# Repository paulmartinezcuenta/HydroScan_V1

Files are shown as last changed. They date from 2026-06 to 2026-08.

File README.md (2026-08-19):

<div align="center">

#  Mechatronics & IoT Engineering Projects

*Centralized repository for the development of unified embedded systems.*






</div>

---

> **💡 Manufacturing Note:** To drastically optimize industrial production costs, the PCBs for both projects (HydroScan and AUTOAMBU) have been unified into a single manufacturing panel (Panelized Gerber), sharing the same manufacturing cycle.

---

##  Project 1: HydroScan (Maritime IoT Node)
**Smart buoy for real-time water quality monitoring.***

<p align="center">
  
  
  
  
</p>

* 📡 **Telemetry:** Real-time environmental data transmission via LTE networks.
* 📍 **Tracking:** Integrated GPS geolocation for precise positioning of the node.
* 🔋 **Power:** Self-sustaining energy system utilizing solar panels to charge and monitor the sensors autonomously.
* 🔬 **Application:** Oceanographic research and environmental monitoring in coastal areas.
* 📁 [**Explore HydroScan Firmware ➔**](./Firmware_HydroScan)

---

## 🫁 Project 2: AUTOAMBU (Automated Respirator)
**Automated respiratory assistance system.**

<p align="center">
  
  
  
  
</p>

* ⚙️ **Actuation & Control:** Precision mechanical control using a DC motor equipped with an encoder and driven by an L298N H-bridge.
* ⚡ **Power Management:** USB Super Fast Charging architecture designed to simultaneously power the circuitry and charge the system.
* 🧠 **Architecture:** Centralized ESP32 32U control logic with dedicated thermal management for continuous and safe operation.
* 📁 [**Explore AUTOAMBU Firmware ➔**](./Firmware_AUTOAMBU)

---

## 👥 Development Team

* ⚡ **Paul** - Hardware Design and PCB Routing 
* 🏗️ **Miguel** - Structural 3D Design
* 💻 **Isaias** - Firmware Development
* 💻 **Alberto** - Firmware Development

---

## 📂 Repository Architecture

| Directory | Description |
| :--- | :--- |
| 🖨️ [**`Hardware_Panelized/`**](./Hardware_Panelized) | Unified KiCad project and joint production Gerber files ready for manufacturing. |
| 💻 [**`Firmware_AUTOAMBU/`**](./Firmware_AUTOAMBU) | Source code (C/C++) and control routines for the medical respirator. |
| 📡 [**`Firmware_HydroScan/`**](./Firmware_HydroScan) | Telemetry logic and sensor reading for the maritime buoy. |
| 📚 [**`Docs/`**](./Docs) | Technical documentation, datasheets, schematics, and 3D models for both systems. |

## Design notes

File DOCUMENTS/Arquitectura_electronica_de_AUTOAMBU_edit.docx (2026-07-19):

Diseño de la estructura electrónica del sistema AUTOAMBU

4.2 Arquitectura electrónica del sistema

Aquí incluirías un diagrama de bloques, no la PCB.

Se explicaría cómo está organizado el sistema:

- Unidad de alimentación.
- Regulación de voltaje.
- Unidad de procesamiento (ESP32).
- Etapa de potencia.
- Sensores.
- Interfaz de usuario.
- Comunicaciones.

4.3 Criterios de diseño de la PCB

Este apartado explica cómo diseñaste la tarjeta antes de hablar de componentes específicos.

Aquí describirías aspectos como:

- Diseño basado en criterios DFM (Design for Manufacturing).
- Cumplimiento de normas IPC.
- Selección del stack-up de la PCB.
- Distribución de bloques funcionales.
- Separación entre potencia y lógica.
- Integridad de señal.
- Integridad de potencia.
- Compatibilidad electromagnética (EMC).

4.4 Distribución física de los componentes

En este apartado ya comenzarías a justificar decisiones concretas.

Por ejemplo:

La distribución física de los componentes se realizó considerando la función eléctrica de cada subsistema y las recomendaciones de diseño establecidas por los fabricantes. Los bloques encargados de la regulación de potencia fueron ubicados próximos a la entrada de alimentación, mientras que la unidad de procesamiento se situó en una región separada de las fuentes de ruido eléctrico generadas por los convertidores conmutados.

Luego explicarías:

- por qué el ESP32 está donde está;
- por qué el regulador está cerca del conector de alimentación;
- por qué los conectores se colocaron en los bordes;
- por qué el driver del motor está cerca del motor.

4.5 Diseño del sistema de alimentación

Aquí entrarías en detalles como:

- Regulador Buck.
- Fuente de 3.3 V.
- Capacitores.
- Diodo Schottky.
- Bobina.
- Anchos de pista.
- Plano de alimentación.

Aquí iría la explicación que hicimos anteriormente sobre el diseño del convertidor Buck.

4.6 Diseño del plano de tierra (Ground Plane)

Este apartado es muy importante porque tu PCB tiene bastante trabajo en ese aspecto.

Podrías explicar:

- plano continuo de tierra;
- retorno de corriente;
- reducción de EMI;
- reducción de impedancia;
- estabilidad del sistema;
- conexión entre capas mediante vías.

4.7 Estrategias de integridad de señal y potencia

Aquí describirías decisiones como:

- capacitores de desacoplo de 100 nF;
- capacitor de 10 µF junto al ESP32;
- pistas cortas;
- reducción del área del lazo de corriente;
- separación entre señales digitales y potencia;
- ubicación del regulador conmutado;
- distribución de planos de alimentación.

4.8 Gestión térmica

En este apartado hablarías de:

- vías térmicas (thermal vias o via-in-pad);
- disipación mediante planos de cobre;
- componentes de potencia;
- reducción de temperatura.

4.9 Diseño orientado a manufactura (DFM)

Aquí explicarías:

- cumplimiento de reglas DRC;
- cumplimiento de capacidades del fabricante (por ejemplo, JLCPCB);
- separación mínima entre pistas;
- diámetros de vías;
- tamaño de pads;
- serigrafía;
- panelización (si aplica).

4.10 Validación del diseño

Finalmente, cerrarías el capítulo indicando cómo verificaste el diseño antes de fabricar la placa:

- revisión del esquemático;
- comprobación de reglas eléctricas (ERC);
- comprobación de reglas de diseño (DRC);
- revisión del modelo 3D;
- generación de archivos Gerber;
- fabricación y ensamblaje.

CAPÍTULO IV

Diseño de la estructura electrónica del sistema AUTOAMBU

Introducción

El sistema AUTOAMBU fue concebido como un asistidor respiratorio automatizado capaz de controlar el proceso de compresión de un resucitador manual tipo Ambu mediante una plataforma electrónica integrada. El diseño electrónico constituye el núcleo del sistema, ya que es responsable de coordinar la adquisición de datos, el procesamiento de información, el control de los actuadores y la administración de la alimentación eléctrica, garantizando un funcionamiento estable y seguro.

El desarrollo de la arquitectura electrónica se realizó bajo criterios de confiabilidad, modularidad y facilidad de manufactura, buscando minimizar las pérdidas eléctricas, mejorar la inmunidad frente al ruido electromagnético y optimizar la distribución térmica de los componentes de potencia. Para alcanzar estos objetivos se empleó el software KiCad como herramienta de diseño asistido por computadora (CAD), permitiendo desarrollar el esquema eléctrico, la placa de circuito impreso (PCB) y la documentación necesaria para su fabricación.

Durante el diseño se aplicaron criterios basados en las recomendaciones de las normas IPC para el dimensionamiento de pistas, separación entre conductores, distribución de componentes y uso de planos de tierra, así como las guías de diseño proporcionadas por los fabricantes de los principales circuitos integrados utilizados en el sistema. Estas prácticas permitieron obtener una tarjeta electrónica orientada a manufactura, con un alto nivel de integración y preparada para operar de manera confiable en aplicaciones de control embebido.

Figura #_#. Diseño final de la placa de circuito impreso (PCB) del sistema AUTOAMBU.

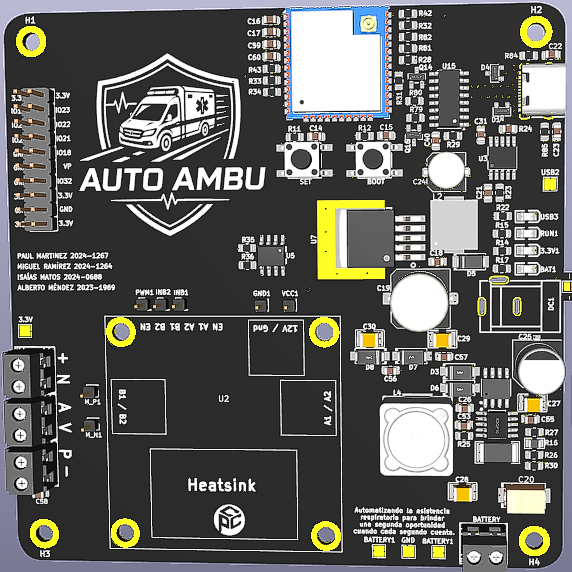
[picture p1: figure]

titulo

Arquitectura electrónica del sistema

Interfaz de entrada y negociación de potencia (USB Tipo-C)

Introducción El sistema AUTOAMBU emplea un conector USB Tipo-C de 16 pines como interfaz principal para la alimentación eléctrica del circuito. A diferencia de las implementaciones convencionales que operan a 5 V, este diseño incorpora un sistema de Power Delivery (PD) destinado a satisfacer las mayores demandas energéticas requeridas por la etapa de potencia y el accionamiento de los actuadores del dispositivo médico. El uso de este estándar garantiza una alta confiabilidad mecánica, reversibilidad de conexión y la capacidad de manejar mayores densidades de corriente.

Colocar imagen del apartado del USB

Negociación de potencia (Power Delivery) Para gestionar los requerimientos energéticos, el circuito incluye el circuito integrado CH224K, un controlador lógico (Sink Controller) diseñado para el protocolo USB Power Delivery. Este dispositivo se interconecta con las líneas de configuración del conector (CC1 y CC2) para establecer comunicación con la fuente externa y solicitar de manera activa un perfil de carga rápida.

Mediante la configuración por hardware de sus pines de control (CFG1, CFG2 y CFG3), el controlador CH224K negocia una salida nominal de 15 V y una capacidad de corriente de hasta 3A. El pin Power Good (PG) se utiliza para señalizar el estado de la negociación hacia las siguientes etapas del sistema, garantizando que los reguladores posteriores solo operen cuando la fuente haya estabilizado la tensión solicitada.

Protección eléctrica y compatibilidad electromagnética (EMC) Considerando la naturaleza de la aplicación médica y los riesgos asociados a transitorios eléctricos durante la conexión del cable, la etapa de entrada fue diseñada con múltiples barreras de protección de estado sólido y filtrado pasivo:

- Supresión de transitorios (TVS): Se implementaron arreglos de diodos supresores de voltaje transitorio (TVS), modelo SM05.TCT, conectados estratégicamente a la línea de alimentación principal y a los canales de comunicación. Los diodos D1 y D4 actúan absorbiendo las descargas electrostáticas (ESD) y limitando los picos de sobretensión tanto en VBUS (V5_1 en el esquemático) como en las líneas CC1 y CC2, derivando la energía perjudicial hacia el plano de tierra antes de que alcance el controlador CH224K o el resto de los componentes sensibles.
- Aislamiento del chasis (Shield Grounding): Para mitigar la interferencia electromagnética (EMI), la carcasa metálica del conector (pines EH) no se conectó rígidamente al plano de tierra del sistema (GND). En su lugar, se diseñó una red de acoplamiento RC en paralelo, compuesta por capacitores de desacoplo de 0.1 µF y resistencias de 1 MΩ (R85 y R84). Esta topología permite drenar de forma segura las interferencias de radiofrecuencia (RF) captadas por el blindaje del cable, a la vez que previene la formación de lazos de tierra (ground loops) de baja frecuencia que podrían afectar la estabilidad analógica del circuito.

Etapa 2

Sistema de gestión de carga y selección de alimentación (Power Path)

Introducción La energía de 15 V proveniente del controlador de Power Delivery se dirige a la etapa de gestión de energía, la cual tiene dos propósitos fundamentales: administrar de manera segura el perfil de carga del paquete de baterías de iones de litio en configuración 3S (12.6 V) y garantizar la continuidad del suministro eléctrico hacia el resto del dispositivo (sistema Power Path).

Colocar imagen del apartado de carga:

Esquemático del circuito de carga basado en el controlador CN3795 y arreglo de diodos para selección de alimentación.

x

CN3795

Para el control de carga se seleccionó el circuito integrado CN3795, un controlador de carga de amplio rango de entrada que opera mediante una topología de conmutación tipo Buck (reductor). Este controlador acciona un MOSFET de canal P (Q1, modelo AO4435) que, en conjunto con el diodo de captura Schottky (D6) y el inductor de potencia (L4, 22 µH), conforma la etapa de potencia encargada de reducir los 15 V de entrada a los 12.6 V requeridos por la batería.

El control del voltaje de flotación se establece a través de un divisor resistivo de precisión (R16 y R27) conectado al pin de retroalimentación (FB). Simultáneamente, la corriente de carga máxima se regula mediante la resistencia de sensado (R13) ubicada entre los pines CSP y BAT del integrado. Este lazo de control dual permite al CN3795 ejecutar las fases de carga de corriente constante (CC) y voltaje constante (CV) exigidas por la química de litio, maximizando la vida útil de las celdas.

Estrategia de aislamiento de tierras (Clean Ground) Un aspecto crítico en el diseño de esta etapa fue la mitigación del ruido eléctrico. Dado que el convertidor de conmutación genera corrientes transitorias de alta frecuencia (di/dt), se implementó una estrategia de tierras separadas para proteger las mediciones analógicas del controlador. Como se observa en el esquemático, se definió una red de "tierra limpia" (GND2) para los pines de referencia del CN3795. Esta red se une al plano de tierra principal de potencia (GND) en un único punto mediante un componente físico de unión o Net Tie (NT1). Esta técnica, conocida como conexión en estrella, evita que las corrientes de retorno de la etapa de potencia circulen por la sección analógica, garantizando una regulación estable.

Gestión de distribución de energía (Power Path) Para asegurar que el sistema AUTOAMBU no se interrumpa al desconectar el cable USB, se diseñó un circuito de selección de fuente de alimentación basado en un arreglo de diodos en configuración OR (D7 y D8).

- Operación con alimentación externa: Cuando el dispositivo está conectado por USB (V5_1 activo a 15 V), el diodo D7 conduce y suministra energía directamente al nodo principal de regulación (VCC_REG). Dado que los 15 V de entrada son superiores a los 12.6 V máximos de la batería, el diodo D8 queda polarizado en inversa, bloqueando el flujo y permitiendo que toda la corriente del cargador se destine exclusivamente a recargar la batería.
- Operación a batería: Al desconectar el cable USB, la tensión V5_1 cae a cero. Inmediatamente, el diodo D8 queda polarizado en directa, permitiendo que la batería asuma la carga del sistema de manera ininterrumpida.

Finalmente, es importante destacar que la alimentación para el actuador mecánico principal (VCC_MOTOR) se extrajo directamente del nodo de la batería y antes del arreglo de diodos. Esta decisión de diseño aísla las severas caídas de tensión y el ruido inductivo generados por los picos de arranque del motor de corriente continua, protegiendo así la estabilidad del nodo de regulación lógica (VCC_REG).

Etapa de regulación lógica (Convertidor Buck 3.3 V)

Introducción La tensión proveniente del bus principal de alimentación (VCC_REG), la cual puede variar entre los aproximadamente 9 V de una batería próxima a descargarse y los 15 V suministrados por el adaptador USB Tipo-C, debe ser reducida y estabilizada para alimentar de forma segura al microcontrolador ESP32 y a la instrumentación de baja potencia. Debido a la considerable diferencia de potencial entre la entrada y la salida requerida, se descartó el uso de reguladores lineales (LDO), ya que generarían una disipación térmica excesiva e ineficiente. En su lugar, se implementó un convertidor de conmutación tipo Buck.

Incluir imagen de la etapa del regulador

Esquemático del regulador reductor LM2576HVS-3.3 para la alimentación del ESP32.

Selección del regulador y filtrado de entrada El núcleo de esta etapa es el circuito integrado monolítico LM2576HVS-3.3 (U7), seleccionado por su robustez, su amplio margen de voltaje de entrada (versión HVS) y su capacidad para suministrar hasta 3 A de corriente continua, garantizando un margen de potencia holgado para los picos de transmisión de radiofrecuencia del ESP32.

Para estabilizar la entrada del regulador, se implementó una red de filtrado desacoplada. El capacitor C19 (470 µF) actúa como un depósito de energía (bulk capacitor) que absorbe los transitorios de baja frecuencia y previene caídas abruptas en el bus VCC_REG durante los ciclos de encendido del regulador. En paralelo, el capacitor cerámico C18 (100 nF) se ubicó lo más cerca posible del pin de entrada (Vin) para derivar a tierra el ruido de alta frecuencia y las interferencias electromagnéticas.

Red de conmutación y salida El proceso de conversión de energía se lleva a cabo mediante la interacción del interruptor interno del LM2576, el inductor L2 (100 µH) y el diodo de captura D5 (B330A).

- Diodo Schottky: La selección del diodo B330A es crítica en esta topología. Al ser un diodo de barrera Schottky, posee un tiempo de recuperación inversa prácticamente nulo y una baja caída de tensión directa. Esto permite que la corriente generada por el campo magnético del inductor circule libremente y de forma eficiente cuando el interruptor interno del regulador se abre (fase de apagado o freewheeling).
- Filtrado de salida: La versión de voltaje fijo del integrado simplifica el diseño al requerir que el pin de retroalimentación (Feedback) se conecte directamente al Nodo de salida. El capacitor C24 (47 µF) se encarga de suavizar el rizado (ripple) de la corriente proveniente del inductor, proporcionando finalmente un plano de 3.3 V limpio y estable para los circuitos lógicos.

Gestión térmica en el diseño físico: Desde la perspectiva del diseño físico (Layout), el LM2576HVS fue seleccionado en un encapsulado de montaje superficial que incorpora una pestaña de disipación (TAB, pin 6). Como se indica en el esquemático, este terminal se conectó directamente a la red de tierra (GND). En la placa de circuito impreso, esta conexión cumple un doble propósito: establecer la referencia eléctrica central del componente y actuar como el puente térmico primario, transfiriendo el calor generado por las pérdidas de conmutación hacia los planos internos de cobre de la PCB para su correcta disipación.

Consideraciones de operación a baja tensión (Modo de programación) Resulta imperativo analizar el comportamiento de esta etapa durante el proceso de programación y depuración del firmware. En este escenario, el dispositivo se conecta a un puerto USB estándar de un ordenador, el cual no cuenta con negociación de Power Delivery, limitando la tensión de entrada en el bus VCC_REG a 5 V y la corriente máxima a 500 mA (estándar USB 2.0).

Bajo estas condiciones operativas, el sistema dispone de una potencia de entrada máxima de 2.5 W. El regulador LM2576HVS-3.3 opera con un diferencial de tensión (dropout) de 1.7 V (5 V a la entrada frente a 3.3 V a la salida), manteniéndose dentro de su margen operativo para garantizar la regulación. Considerando una eficiencia típica de conversión del 75% para este diferencial, la etapa es capaz de suministrar aproximadamente 560 mA netos a la salida de 3.3 V. Si bien este margen energético podría ser restrictivo si el microcontrolador activara sus periféricos de radiofrecuencia a máxima potencia, es holgadamente suficiente para satisfacer el consumo de la unidad de procesamiento durante el modo de descarga y escritura en la memoria flash, garantizando una programación estable sin requerir la conexión de la batería o de una fuente de alta capacidad.

Etapa de potencia y control de actuación (Driver de Motor)

Introducción La etapa de actuación mecánica es el componente crítico del sistema AUTOAMBU, encargado de proveer el torque y la velocidad necesarios para comprimir el resucitador manual de forma cíclica y controlada. Para facilitar el mantenimiento, optimizar el manejo térmico y modularizar el sistema, se optó por externalizar el driver de potencia utilizando un módulo comercial basado en el puente H L298N. Este módulo se interconecta con la tarjeta de control principal mediante una interfaz de pines (headers) diseñada específicamente para enviar las señales lógicas y canalizar la energía requerida por el motor.

Añadir imagen de etapa de puente H y conector de motor

Esquemático de las interfaces de conexión para el módulo L298N y la retroalimentación del encoder del motor.

Interfaz de control del Puente H:

Como se aprecia en la sección derecha del esquemático, la interfaz hacia el módulo L298N consta de líneas de potencia y de control lógico.

- Aislamiento de energía: Para la alimentación de fuerza, se expuso el nodo VCC_MOTOR. Como se definió en la etapa de gestión de energía, esta línea proviene directamente de la batería, evitando que los picos inductivos generados durante el arranque o la inversión de giro del motor afecten el nodo regulado de la lógica del sistema. Ambas placas comparten un nodo común (GND1 a GND) para establecer la misma referencia eléctrica en las señales de control.
- Señales de conmutación: El control de giro y velocidad se gestiona a través de tres líneas digitales provenientes del microcontrolador ESP32. Los pines IO14_1 (INA) e IO27_1 (INB) determinan el sentido de rotación del motor al conmutar los transistores del puente H. Por su parte, la línea IO26_1 proporciona una señal de modulación por ancho de pulso (PWM), la cual regula el ciclo de trabajo de la etapa de potencia y, en consecuencia, la velocidad de compresión del actuador mecánico.

Retroalimentación de posición (Interfaz de Encoder) Para que el sistema AUTOAMBU opere como un lazo de control cerrado y garantice un volumen de compresión exacto, es imprescindible conocer la posición angular del motor en todo momento. La sección izquierda del esquemático muestra la interfaz diseñada para conectar el encoder de cuadratura acoplado al eje del motor.

- Acondicionamiento de señal: Las señales de los canales del encoder ingresan a la tarjeta a través del conector tipo bornera (DB125) y se dirigen a los pines de interrupción del ESP32 (IO25_1 e IO33_1). Para garantizar la integridad de estas señales digitales, se implementaron resistencias de polarización (pull-up) de 4.7 kΩ (R33 y R34) atadas al riel de 3.3 V. Esto asegura estados lógicos definidos frente al ruido electromagnético ambiental.
- Filtrado: Se incluyó un capacitor de desacoplo (C58 de 0.1 µF) en la alimentación del sensor para mitigar fluctuaciones y evitar falsos conteos de pulsos que podrían desestabilizar el algoritmo de control de posición del resucitador. Además, se añadieron puntos de prueba (TestPoints M_N1 y M_P1) para facilitar la calibración y el diagnóstico de las señales con osciloscopio durante la validación del sistema.

Unidad central de procesamiento y control (ESP32)

Introducción y justificación del microcontrolador El núcleo lógico del sistema AUTOAMBU está conformado por el módulo de procesamiento ESP32, encargado de adquirir los datos de los sensores, ejecutar los algoritmos de control de lazo cerrado para el actuador mecánico y gestionar las comunicaciones del dispositivo.

Para este prototipo, se implementó el módulo ESP32-WROOM-32U. Aunque la hoja de datos más reciente de Espressif recomienda la variante ESP32-WROOM-32UE para nuevos diseños debido a mejoras de eficiencia en el silicio, se optó por la versión 32U para aprovechar la disponibilidad inmediata de inventario durante la fase de desarrollo. Dado que ambos módulos poseen compatibilidad estricta de pines (pin-to-pin) y un factor de forma idéntico, la arquitectura de la tarjeta permite una futura migración a la versión 32UE sin necesidad de modificar el diseño de la placa de circuito impreso (PCB).

Anadir imagen del esquematico ESP-32 32U

Esquemático del microcontrolador ESP32-WROOM-32U, interfaz UART y circuito de auto-programación.

Acondicionamiento de energía Los módulos ESP32 generan altos picos de consumo de corriente (transitorios) durante la inicialización y la transmisión de datos por radiofrecuencia. Para asegurar la estabilidad lógica y evitar reinicios inesperados (Brown-out resets), se implementó un filtro capacitivo dedicado en su pin de alimentación principal de 3.3 V.

Anadir imagen del esquemático filtrado de esp32

Red de filtrado capacitivo para la alimentación del ESP32

Como se detalla en el esquemático correspondiente, la red de filtrado consta de un capacitor electrolítico o de tantalio de 10 µF (C17) que actúa como reserva de energía para los picos de baja frecuencia, en paralelo con un capacitor cerámico de 100 nF (C16) destinado a derivar a tierra el ruido de alta frecuencia proveniente de la etapa de conmutación del regulador Buck.

Interfaz de comunicación y circuito de auto-programación Para facilitar la carga de firmware y la depuración serial sin requerir herramientas externas, se integró el puente USB-a-UART CH340C (U15). Un aspecto destacable del diseño es la inclusión del circuito de auto-programación (Auto-Program Circuit) basado en los transistores NPN 2N3904 (Q14 y Q16). Este arreglo lógico traduce las señales DTR y RTS provenientes del puerto USB en la secuencia correcta de pulsos lógicos bajos sobre los pines EN (Reset) y BOOT (IO0) del ESP32. Esto permite que el entorno de desarrollo (IDE) ponga al microcontrolador en modo de descarga de forma automática, eliminando la necesidad de interactuar con botones físicos en la placa.

Acondicionamiento analógico para medición de batería Monitorizar la autonomía del dispositivo médico es una función crítica. Dado que el paquete de baterías opera a un voltaje máximo de 12.6 V, el cual excede el límite de 3.3 V del convertidor analógico-digital (ADC) del ESP32, se diseñó una etapa de sensado dedicada.

Anadir imagen del esquemático de batería medidor

Circuito acondicionador con amplificador operacional para medición del nivel de batería.

La tensión de la batería (V_BATTERY_1) se reduce mediante un divisor resistivo conformado por R36 (30 kΩ) y R35 (10 kΩ), entregando un máximo teórico de 3.15 V. Para evitar que el capacitor de muestreo interno del ADC del microcontrolador altere esta medición al drenar corriente del divisor, se incorporó un amplificador operacional LM358DR (U5A) configurado como seguidor de tensión (buffer). Esta etapa proporciona una alta impedancia de entrada hacia el divisor y una baja impedancia de salida hacia el pin analógico VN_1, garantizando lecturas precisas, las cuales son filtradas adicionalmente por el capacitor C60 (0.1 µF).

Expansión y conectividad periférica Finalmente, para integrar la pantalla, los sensores externos y el encoder, se dispuso un conector principal de 20 pines (H2).

(Aquí debes insertar la imagen esquematico de conector de pines

Interfaz de periféricos y resistencias de acondicionamiento I²C.

En esta sección se incluyeron resistencias de pull-up de 4.7 kΩ (R28 y R32) para los buses de comunicación I²C, asegurando los estados lógicos altos necesarios para los dispositivos esclavos de la interfaz de usuario. Asimismo, se incorporaron jumpers de selección (JP5 y JP7) apoyados por resistencias pull-down de 10 kΩ, dotando al sistema de flexibilidad para configurar parámetros por hardware o modificar el comportamiento del dispositivo sin alterar el firmware.

Sistema de nodos de prueba para diagnóstico (Test Points)

Introducción En el diseño de sistemas médicos y de control embebido industrial, es fundamental prever etapas que faciliten la puesta en marcha, la depuración en tiempo real y la validación segura del hardware. Para evitar cortocircuitos accidentales durante la manipulación con puntas de osciloscopio o multímetros sobre los pines de los componentes superficiales, se integró una red de nodos de prueba físicos (Test Points) distribuidos estratégicamente en los rieles principales de alimentación y referencia del circuito.

Añadir imagen de los test point

Esquemático de los nodos de prueba asignados a los buses de potencia y tierra del sistema.

Justificación técnica de los nodos de medición La red de puntos de prueba expone los voltajes críticos del sistema, permitiendo evaluar la eficiencia de las etapas de regulación, la caída de tensión en líneas de alta corriente y la calidad del filtrado contra el rizado eléctrico:

- Nodo de Entrada Principal (USB2 / V5_1): Permite verificar de manera directa el éxito de la negociación de carga rápida gestionada por el CH224K. A través de este punto se valida si la fuente externa está entregando de forma estable la tensión de entrada nominal antes de ingresar a la etapa de carga de la batería.
- Nodo de Regulación Lógica (3.3V3 / 3.3V): Posicionado a la salida del convertidor conmutado LM2576. Es el punto crítico para diagnosticar la estabilidad de la alimentación analógica y digital del ESP32, permitiendo medir con osciloscopio cualquier acoplamiento de ruido de conmutación o caídas de tensión bruscas cuando el microcontrolador activa sus periféricos inalámbricos.
- Nodos de Fuerza del Actuador (BATTERY1 y BATTERY2 / VCC_MOTOR): El diseño incorpora dos puntos de prueba independientes para el bus que alimenta el puente H del motor. Esta decisión responde a la necesidad de evaluar el comportamiento dinámico de la batería bajo carga. Al contar con dos terminales en diferentes ubicaciones del trazo físico, es posible medir la impedancia de la pista de potencia y la caída óhmica ( I⋅R ) provocada por las corrientes transitorias de arranque y frenado del motor.
- Nodo de Referencia Global (GND3 / GND): Proporciona un punto de conexión seguro y de baja impedancia para la pinza de tierra de los instrumentos de medición. Al centralizarse con los demás puntos de prueba, minimiza el área del lazo de retorno de las puntas de prueba, evitando la captura de ruido electromagnético ambiental durante las lecturas.

Desarrollo electronico de ambu:

Primeramente establecimos la maquina de estado de nuestro producto

Introducción al diseño electrónico.

Arquitectura electrónica del sistema.

Selección de componentes.

Diseño esquemático.

Diseño de la PCB.

Gestión de alimentación.

Sistema de control.

Sensores.

Actuadores.

Protección eléctrica.

Comunicación entre módulos.

Validación del diseño.

INFORME DE EVALUACIÓN TÉCNICA DE DISEÑO DE PCB

Proyecto: Módulo de Control de Potencia y Lógica "AUTO AMBU" / "HYDROSCAN"
Estado del Arte: Diseño Finalizado (Fase de Verificación de Reglas de Diseño - DRC)
Voltaje de Operación Máximo: 15V DC
Plataforma de Diseño: KiCad EDA

-ANÁLISIS DE CUMPLIMIENTO DE LA NORMA IPC-2221

La norma IPC-2221B (Generic Standard on Printed Board Design) rige los parámetros de seguridad eléctrica, aislamiento y geometría de conductores.

Distancias de Aislamiento Eléctrico (Clearance)

- Requisito de la Norma: Para un voltaje pico de 15V DC, la Tabla 6-1 de la IPC-2221 exige un aislamiento mínimo de 0.10 mm (3.9 mils) en conductores internos (B1), externos desnudos (B2) y externos con máscara de soldadura (B4).
- Evaluación del Diseño: El diseño implementa una separación general entre pistas, planos y pads estimada entre 0.20 mm y 0.25 mm.
- Dictamen: CUMPLE Y SUPERA. El diseño excede el mínimo normativo en más de un 100%, ofreciendo un margen de seguridad crítico contra contaminación superficial o humedad sin penalizar los costos de fabricación estándar.

Gestión Térmica y Reglas de Potencia

- Requisito de la Norma: Las pistas deben dimensionarse para limitar el aumento de temperatura (Δ T) por densidad de corriente y disipar el calor eficientemente.
- Evaluación del Diseño: Se evidencia un bloque de potencia masivo con una zona dedicada para disipador (Heatsink), acompañada de técnicas de alivio térmico (thermal relief) en pads expuestos a planos para asegurar una correcta soldabilidad industrial.
- Dictamen: CUMPLE. Las áreas de cobre y la zonificación periférica de la etapa de potencia respetan los criterios de control de gradientes térmicos.

Reducción de Resistencia e Inductancia de Conducción

- Via-in-Pad (Vías en Pad): Implementada en pads de tierra de componentes críticos. Esta técnica reduce la inductancia parásita de la conexión a masa casi a cero en comparación con las pistas de enrutamiento tradicionales hacia vías externas.
- Via Stitching (Costura de Vías de GND): La inclusión de múltiples vías en paralelo en las áreas de retorno de potencia y bajo el disipador disminuye drásticamente la resistencia óhmica óhmica total (R = ρ ⋅ L / A) y maximiza la conductividad térmica hacia las capas internas o posteriores.

Inmunidad al Ruido Conducido (Red de Distribución de Potencia - PDN)

- Distancia al Regulador Switching: El lazo conmutado (LM25XX) se ubica a una distancia física de 20 mm respecto al microcontrolador (ESP32-WROOM-32D).
- Red de Desacoplo Concéntrica: Se implementó un filtro de doble polo compuesto por un capacitor de 10 µF (baja frecuencia/sostén de carga) y uno de 0.1 µF / 100 nF (alta frecuencia/atenuación de picos de conmutación de 150 kHz), posicionados en un estado de "fusión geométrica" (distancia mínima) a los pines VDD/GND del chip receptor. Esto neutraliza la reactancia inductiva de las pistas viajeras de 20 mm.

Blindaje contra Interferencia Electromagnética (EMI)

- Via Shielding (Apantallamiento por Vías): Las pistas de datos sensibles están flanqueadas por líneas de vías conectadas sólidamente al plano de potencial cero (GND). Esto crea una barrera de blindaje físico (Jaula de Faraday bidimensional) que absorbe la diafonía (crosstalk) radiada por la actividad conmutada del circuito de potencia cercano.

Mitigación por Software: El compromiso de diseño de mantener deshabilitadas las etapas de RF (Wi-Fi/Bluetooth de la antena del ESP32) elimina el riesgo de intermodulación aérea o susceptibilidad electromagnética en la banda de 2.4 GHz.

COMPATIBILIDAD CON MANUFACTURA COMERCIAL (DFM)

El diseño ha sido verificado visual y geométricamente frente a las capacidades técnicas de los pools de fabricación estándar de la industria (clase de precisión general):

- Ancho y Espaciado de Conductores: Al mantenerse por encima de las 6 mils (0.152 mm), la placa califica para procesos de fabricación estándar de bajo costo, garantizando una tasa de rendimiento (yield) cercana al 100%.

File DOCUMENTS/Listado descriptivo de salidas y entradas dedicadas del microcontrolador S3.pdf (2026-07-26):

### Listado descriptivo de salidas y entradas dedicadas del

microcontrolador S3-1.

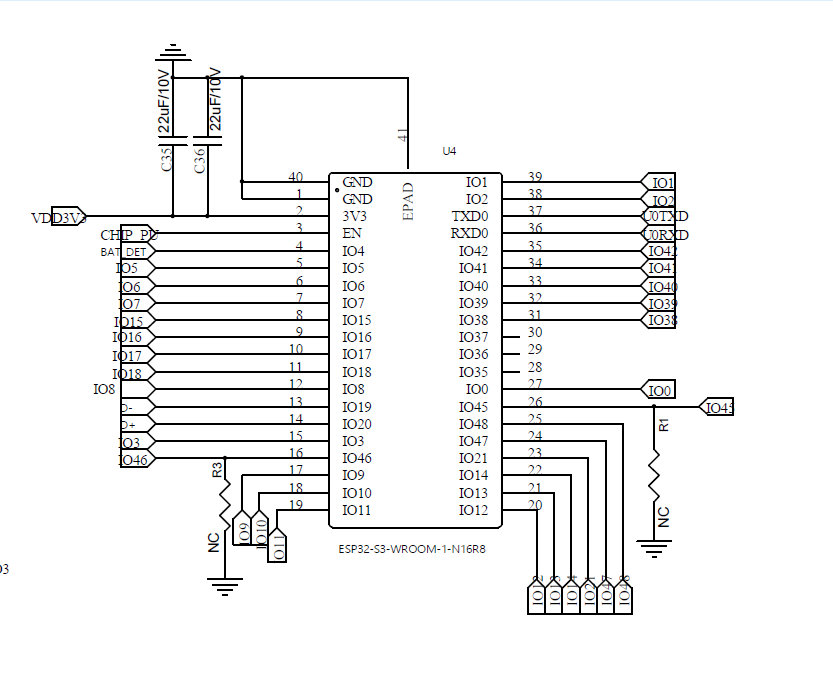
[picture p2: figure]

-I01= Medidor de batería en PCB
-I02 = Sensor de temperatura
-U0TXD= UART TX, pin disponible en regleta -U0RXD= UART RX, pin disponible en regleta -IO42= X No está en regleta y no usar, función JTAG. -IO41= X No está en regleta y no usar
-IO40= X No está en regleta y no usar
-IO39= X No está en regleta y no usar
-IO38= INT del Giroscopio
-IO0= X No está en regleta y no usar, función BOOT.
-IO45= X No está en regleta, este tiene un resistor externo a tierra. -I048= Esta libre en regleta.
-I047= Este pin está en TF CARD para guardar datos DATA0 (MP3T-F) -I021= Pin CLK (MP3T-F)
-I014=Pin CMD (MP3T-F)
-I013= DATA 3 (MP3T-F)
-I012= Esta libre en regleta. -IO11= Esta libre en regleta.
-IO10= Esta libre en regleta.
-IO9= SDA I2C También esta en regleta disponible
-IO46= X No está en regleta y no usar,
-IO3= Medidor de Voltaje para paneles solares, divisor resistivo 100K -IO20= USB+
-IO19= USB-
-IO8= SCL I2C También esta en regleta disponible

MODULO TF CARD
(MP3T-F)

Paneles solares

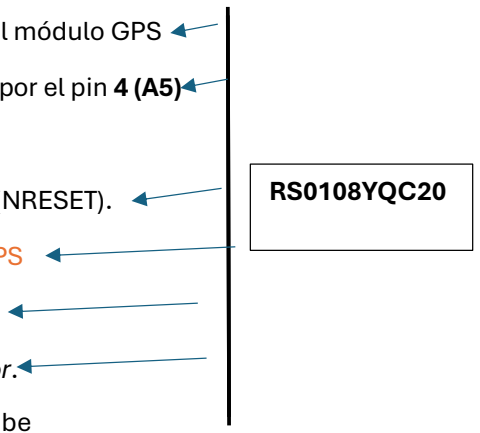
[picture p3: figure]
RS0108YQC20

-IO18= conectado a B6 del IC el cual conectado al pin 71 (TXD) del módulo GPS -IO17= Entra al conversor por el pin 13 (B5) y sale rebajado a 1.8V por el pin 4 (A5) con el nombre AX_RXD.
-IO16= B4 está asignado a la señal de reinicio del módulo celular (NRESET). -IO15= Powerkey aquí puedes des alimentar completamente el GPS -IO7= B3 de IC. AX_DTR se usa para controlar modo sleep del GPS
-IO6= B2 de IC. AX_RI este pin se usa para la línea de Ring Indicator. El módulo la pone en nivel bajo para avisarle al ESP32 cuando recibe una llamada, un mensaje SMS o datos de red pendientes.
-IO5= Asignado para el switch en PCB apagar sensores o luz
-IO4= BAT_DET aquí un medidor de batería el modulo.

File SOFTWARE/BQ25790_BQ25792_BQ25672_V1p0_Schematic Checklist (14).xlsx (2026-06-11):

 | BQ25790/2/8 and BQ25672 Schematic Review
 |  |  |  |  |  |  |  |  |  | BQ25792/BQ25798/BQ25672
 |  |  |  |  |  |  |  |  |  | BQ25790
 |  |  |  |  |  |  |  |  | NOTE: BQ25672 requires only 3x10uF
NOTE: All capacitors are assumed to be ceramic with voltage voltage rating = at least 2 x the pin's max expected voltage
Pin | QFN | WCSP | Opt/Rec/Req | Component | Min | Typ | Max | EXPLANATION | COMMENTS | LAYOUT GUIDANCE
VAC1 | 9 | H1 | Optional | CVAC1 |  | 100n F |  | VAC1 sense line filter capcacitor | Connect to VBUS if ACDRV1 not used.
VAC2 | 8 | G1 | Optional | CVAC2 |  | 100 nF |  | VAC2 sense line filter capcacitor | Connect to VBUS if ACDRV2 not used.
ACDRV1 | 11 | H2 | Optional | QACDRV1 |  | 30 V Nch |  | NFETs for input source MUX | Connect to ground if ACDRV1 not used.
 |  |  |  | DACDRV1 |  | 12V |  | Zener clamp to protect FET gate
 |  |  |  | RACDRV1 |  | 294 Ω |  | Softstart resistor
 |  |  |  | CACDRV1 |  | 1 nF |  | Softstart capacitor
ACDRV2 | 10 | G2 | Optional | QACDRV2 |  | 30 V Nch |  | NFETs for input source MUX | Connect to ground if ACDRV2 not used.
 |  |  |  | DACDRV2 |  | 12V |  | Zener clamp to protect FET gate
 |  |  |  | RACDRV2 |  | 294 Ω |  | Softstart resistor
 |  |  |  | CACDRV2 |  | 1 nF |  | Softstart capacitor
VBUS | 2,3 | A1,B1, C1 | Required | CVBUS-BYP |  | 0.1 uF |  | VBUS high frequency noise bypass capacitor
 |  |  | Required | CVBUS-BULK |  | 2 x 10uF |  | VBUS bulk capacitors
REGN | 5 | E1 | Required | CREGN | 4.7 uF |  |  | REGN linear regulation output capacitor |  | Place close to REGN pin and PGND, priority 2.
PMID | 29 | A2,B2,C2,D2,E2 | Required | CPMID-BYP |  | 0.1 uF |  | PMID high frequency noise bypass capacitor | Critical for device operation and minimizing EMI. | Place as close as possible to PMID and GND pins using as few vias as possible, priority 1
 |  |  | Required | CPMID-BULK |  | 3 x 10uF* |  | PMID bulk capacitors | Input capacitance for the converter *BQ25796 requires 2 additional, parallel 33 uF low ESR polarized capacitors | Place as close as possible to PMID and GND pins using as few vias as possible, priority 1
SYS | 25 | A6,B6,C6,D6,E6 | Required | CSYS-BYP |  | 0.1 uF |  | SYS high frequency noise bypass capacitor | Critical for device operation and minimizing EMI | Place as close as possible to SYS and GND pins using as few vias as possible, priority 1
 |  |  | Required | CSYS-BULK |  | 5 x 10uF -79x 3 x 10uF -672 |  | SYS bulk capacitors | Output capacitance for the converter | Place as close as possible to SYS and GND pins using as few vias as possible, priority 1
BAT | 22,23 | A7,B7,C7,D7,E7 | Required | CBAT |  | 2 x 10uF |  | BAT bulk capacitors |  | Place close to BAT pin and PGND, priority 2.
BATP | 18 | G7 | Required | RBATP |  | 100 Ω |  | BAT+ remote sense isolation resistor | Can short to IC BAT pin if remote sense not needed.
SW1 | 28 | A3,B3,C3,D3,E3 | Required | L1 | 1 uH |  | 2.2 uH | Inductor buck side connection | 1 uH for fSW = 1.5 MHz and 2.2 uH for fSW = 750 kHz | Required to route SWx traces under the IC and then uses vias to connect to inductor if on top layer.
 |  |  | Optional | RSNUB1, CSNUB1 |  | not shown |  | RC snubber to reduce EMI | 603 footprint components, sized on working PCB using empirical measurements. Decreases efficiency by ~0.5% when properly sized | Place close to SWx and PGND, priority 1. If placed on bottom layer, use multiple vias back to top.
BTST1 | 4 | D1 | Required | CBTST1 |  | 0.047 uF |  | Bootstrap capacitor for buck side FET gate drive
SW2 | 26 | A5,B5,C5,D5,E5 | Required | L1 | 1 uH |  | 2.2 uH | Inductor boost side connection | 1 uH for fSW = 1.5 MHz and 2.2 uH for fSW = 750 kHz | Required to route SWx traces under the IC and then uses vias to connect to inductor if on top layer.
 |  |  | Optional | RSNUB2, CSNUB2 |  | not shown |  | RC snubber to reduce EMI | 603 footprint components, sized on working PCB using empirical measurements. Decreases efficiency by ~0.5% when properly sized | Place close to SWx and PGND, priority 1. If placed on bottom layer, use multiple vias back to top.
BTST2 | 19 | F7 | Required | CBTST2 |  | 0.047 uF |  | Bootstrap capacitor for boost side FET gate drive
PROG | 20 | F5 | Required | RPROG |  | *Ω |  | Sets default converter switching frequency and either 1S, 2S, 3S or 4S charging | See datasheet section titled PROG Pin Configuration for resistor sizes
ILIM_HIZ | 17 | F4 | Required | RLIM |  | *Ω |  | Program ILIM_HIZ voltage to set desired IINDPM by connecting a resistor divider from pull up rail to ILIM_HIZ pin then 100 kW resistor to ground. When the pin voltage is below 0.75V, the buck-boost converter enters non-switching mode with REGN on. | VILIM_HIZ = 1V + 800 mW x IINDPMmax IINDPM I2C register can be written to lower value. ILIM_HIZ can be disabled in I2C. ILIM_HIZ can be pulled directly to REGN to set max I2C register value (3.3A).
TS | 16 | H7 | Required (if not disabled in I2C register) | RTS-TOP |  | *Ω |  | Resistor divider to set window for thermistor temperature-based battery charging profile | If TS feature not used, use equations to set V(TS) to ~60% of VREF to hardware disable or I2C bit to software disable.
 |  |  | Required (if not disabled in I2C register) | RTS-BOT |  | *Ω |  |  |  | Connect RTS_BOT to AGND. Kelvin connect resistor divider midpoint to pin routed away from traces/pours/planes with switching noise.
STAT | 1 | F1 | Recommended | RSTAT |  | 2.2 kΩ |  | LED pull up resistor for open drain STAT pin.
 |  |  | Optional | DSTAT |  | green or red |  | Charging status indicating LED
SDRV | 24 | F6 | Optional | QSDRV |  | 30 V Nch |  | The driver pin of the external ship FET. The ship FET is always turned on when ship mode is disabled, and it keeps off when the charger is in ship mode or shutdown mode. | Connect a 0402 / 50V / 1nF ceramic capacitor from SDRV to BAT or GND when the ship FET is not used.
/CE | 13 | G4 | Required | RPULLUP | 2.2 kW |  | 10 kW | Active low, open drain charge enable | Can be tied to GND but recommended to be tied to host GPIO with pull up resistor. Cannot be left floating.
/INT | 21 | G5 | Optional | RPULLUP | 2.2 kW |  | 10 kW | Active low, open drain INT pulse | Can be left floating but recommend to to tied to host GPIO with pull up resistor.
/QON | 12 | G3 | Optional |  |  |  |  | A logic low on this pin with tSM_EXIT duration turns on ship FET to force the device to exit the ship mode. A logic low on this pin with tRST duration resets system power by turning off the ship FET for tRST_SFET (also setting the charger in HIZ mode when VBUS is high) and then turning on ship FET (also disabling the charger HIZ mode) to provide full system power reset | The pin has an internal pull up so it not used it should be left floating. Can be tied to a mechanical push button or host GPIO.
SDA | 15 | H5 | Required | RPULLUP | 2.2 kW |  | 10 kW | I2C data line | Needs pull up resistor to 1.8 V to 3.3 V
SCL | 14 | H4 | Required | RPULLUP | 2.2 kW |  | 10 kW | I2C clock like | Needs pull up resistor to 1.8 V to 3.3 V
D+ | 6 | F2 | Optional |  |  |  |  | USB BC 1.2 communication lines | Connect to USB port in order to set charger input current (IINDPM) register to port capability per USB BC 1.2 spec. Host is expected to perform enumeration. If not used, leave floating for unkown adapter and IINDPM=3A. ILIM_HIZ resistor clamps maximum input current.
D- | 7 | F3 | Optional
BATN (790 only) | na | G6 | Required | RBATN |  | 100 Ω |  | BAT- remote sense isolation resistor | Can short to IC GND pin if remote sense not needed.
/PG (790 only) | na | H3 | Optional | RPULLUP | 2.2 kW |  | 10 kW | Active low, open drain input power good indicator | Can be left floating but recommend to to tied to host GPIO with pull up resistor.
IBAT (790 only) | na | H6 | Optional | RIBATP |  | 10 kW |  | Current source output proivding 25 uA per 1A charge current. | Parallel 100 pF capacitor is recommended to minimize ripple.
GND | 27 | A4,B4,C4,D4,E4 | Required |  |  |  |  | IC GND return | Separate PGND and AGND, connected only at GND pins is recommended by not required as long as power path (VBUS, PMID, SYS, BAT) grounds are routed away from AGND. REGN is technically PGND but difficult to route. | Required to route to internal/bottom layer under the IC but also provide GND trace on top layer for connecting PMID and SYS capacitor grounds

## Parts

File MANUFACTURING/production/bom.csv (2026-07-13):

Designator | Footprint | Quantity | Value | LCSC Part #
3.3V1, BAT1, RUN1, USB3 | LED0805-FD-GREEN | 4 | YLED0805G | C25170728 | _
3.3V2 | TestPoint_Pad_2.5x2.5mm | 1 | 3V |  | x
3.3V3, BATTERY1, GND3, USB2 | TestPoint_Pad_2.0x2.0mm | 4 | TestPoint |  | x
5V1 | TestPoint_Pad_2.5x2.5mm | 1 | 5V |  | x
C14, C15, C22, C23, C26, C55, C56, C57, C58, C59, C60, C61, C62, C63, C64 | 805 | 15 | 0.1uf |  | )
C16, C18, C31, C40 | 805 | 4 | 100nf |  | )
C17, C32, C33, C34 | 805 | 4 | 10uf_25v |  | )
C19 | C_Elec_10x10.2 | 1 | 470uf | C72518 | )
C20 | CAP-SMD_L7.3-W4.3-R-RD | 1 | CA45-D035K226T | C126947 | )
C21 | 805 | 1 | 1uf |  | )
C24 | C_Elec_6.3x7.7 | 1 | 47uf | C72523 | _
C25 | CAP-SMD_BD8.0-L8.3-W8.3-LS9.1-FD | 1 | RVT1V221M0810 | C3340 | _
C27, C28, C29, C30 | C1210 | 4 | CL32B106KBJNNNE | C138687 | )
C53 | 805 | 1 | 220nF |  | )
D1, D4 | SOT-23-3_L2.9-W1.3-P0.95-LS2.4-BR | 2 | SM05.TCT | C85197 | _
D3, D6, D7, D8 | SMA_L4.4-W2.8-LS5.4-R-RD | 4 | SS54_C22452 | C22452 | )
D5 | SMA_L4.3-W2.6-LS5.1-RD | 1 | B330A | C52037930 | _
DC1 | DC-IN-TH_DC-470-2.1GP | 1 | DC-470-2.1GP | C194407 | )
DC_BOOST_1 | HDR-TH_4P-P2.54-V-M | 1 | PZ254V-11-04P_C2691448 | C2691448 | _
GND1 | PinHeader_1x01_P2.00mm_Vertical | 1 | PH_GND |  | _
GND2 | TestPoint_Pad_2.5x2.5mm | 1 | GND |  | _
H2_2, H5 | HDR-TH_20P-P2.54-V-M-R2-C10-S2.54 | 2 | 2.54-2*10 | C5116480 | )
H5.1, H5.2 | HDR-TH_16P-P2.54-V-M_2 | 2 | HX PZ2.54-1X16P ZZ | C42372508 | )
H7.1, H7.2, H7.3, H7.4 |  | 4 |  |  | X
INB1 | PinHeader_1x01_P2.00mm_Vertical | 1 | INB1 |  | X
INB2 | PinHeader_1x01_P2.00mm_Vertical | 1 | INB2 |  | X
J1 | MPU6050_Module | 1 | Conn_01x08_Pin |  | X
J2 | PinHeader_1x03_P2.54mm_Vertical | 1 | Conn_01x03_Pin |  | X
L2 | IND-SMD_L8.5-W8.0_PCC-M0854M | 1 | PSPMAA0805-101M-ANP | C2962892 | _
L4 | IND-SMD_L12.3-W12.3_SMDRI127 | 1 | SMDRI127-220MT | C9905 | )
M_N1 | PinHeader_1x01_P2.00mm_Vertical | 1 | M_N |  | _
M_P1 | PinHeader_1x01_P2.00mm_Vertical | 1 | TestPoint |  | _
PWM1 | PinHeader_1x01_P2.00mm_Vertical | 1 | PWM |  | _
Q1 | SOP-8_L5.0-W3.8-P1.27-LS6.0-BL | 1 | AO4435_C2944310 | C2944310 | )
Q14, Q16 | SOT-23-3_L2.9-W1.3-P1.90-LS2.4-TR | 2 | 2n3904S-RTK/PS_C18536 | C18536 | _
R1 | RES-ADJ-SMD_3P-L3.0-W3.8-P1.75-BR | 1 | TC33X-2-103E | C719176 | )
R11, R12, R24, R26, R29, R31, R35 | 805 | 7 | 10k |  | _
R13 | R2512 | 1 | YLRY12-3-60F | C22468068 | )
R14, R15, R17, R22 | 805 | 4 | 2.2k |  | _
R16 | R0805 | 1 | RC0805FR-07390KL | C137535 | )
R23, R79, R80 | 805 | 3 | 1k |  | _
R25 | 805 | 1 | 120 |  | )
R27 | 805 | 1 | 41.2K | C2077335 | )
R28, R32, R33, R34, R37, R38 | 805 | 6 | 4.7K |  | )
R30, R39, R41 | 805 | 3 | 100K |  | )
R36 | 805 | 1 | 30k |  | )
R40 | 805 | 1 | 6.8k |  | )
R81, R82 | 805 | 2 | 0 |  | _
R84, R85 | 805 | 2 | 1M |  | )
SW2 | SW-SMD_4P-L6.0-W6.0-P4.50-LS8.2 | 1 | BOOT | C7528752 | _
SW4 | SW-SMD_4P-L6.0-W6.0-P4.50-LS8.2 | 1 | RESET | C7528752 | _
TP1 | TestPoint_THTPad_D4.0mm_Drill2.0mm | 1 | TDS_1 |  | X
TP2 | TestPoint_THTPad_D4.0mm_Drill2.0mm | 1 | TDS_2 |  | X
U1 | SOT-23-5_L3.0-W1.7-P0.95-LS2.8-BL | 1 | SY6280AAC | C55136 | )
U10, U11, U8, U9 | CONN-TH_2P-P3.81_DB125-3.81-2P-BK-S | 4 | DB125-3.81-2P-BK-S | C430618 | )
U15 | SOIC-16_3.9x9.9mm_P1.27mm | 1 | CH340C |  | )
U16 | ESP32-WROOM-32U | 1 | ESP32-WROOM-32D |  | )
U2 | L298N-module-43x43mm | 1 | L298N |  | X
U3 | ESSOP-10_L4.9-W3.9-P1.0-LS6.0-TL-EP | 1 | CH224K | C970725 | )
U4 | SSOP-10_L4.9-W3.9-P1.00-LS6.0-BL | 1 | CN3795 | C150555 | )
U5 | SOIC-8_L5.0-W4.0-P1.27-LS6.0-BL | 1 | LM358DR | C5423 | _
U7 | PG-TO-263-5_L10.2-W8.7-P1.70-LS14.4-BR | 1 | LM2576HVS-3.3 | C347436 | )
USB1 | USB-C-SMD_TYPE-C-16PIN-2MD-073 | 1 | TYPE-C 16PIN 2MD | C2765186 | _
VCC1 | PinHeader_1x01_P2.00mm_Vertical | 1 | M_VCC

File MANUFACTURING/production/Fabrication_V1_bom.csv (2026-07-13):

Designator | Footprint | Quantity | Value | LCSC Part #
3.3V1, BAT1, RUN1, USB3 | LED0805-FD-GREEN | 4 | YLED0805G | C25170728
3.3V2 | TestPoint_Pad_2.5x2.5mm | 1 | 3V
3.3V3, BATTERY1, BATTERY2, GND3, USB2 | TestPoint_Pad_2.0x2.0mm | 5 | TestPoint
5V1 | TestPoint_Pad_2.5x2.5mm | 1 | 5V
C14, C15, C22, C23, C26, C55, C56, C57, C58, C59, C60, C61, C62, C63, C64 | 0805 | 15 | 0.1uf
C16, C18, C31, C40 | 0805 | 4 | 100nf
C17, C32, C33, C34 | 0805 | 4 | 10uf_25v
C19 | C_Elec_10x10.2 | 1 | 470uf | C72518
C20 | CAP-SMD_L7.3-W4.3-R-RD | 1 | CA45-D035K226T | C126947
C21 | 0805 | 1 | 1uf
C24 | C_Elec_6.3x7.7 | 1 | 47uf | C72523
C25 | CAP-SMD_BD8.0-L8.3-W8.3-LS9.1-FD | 1 | RVT1V221M0810 | C3340
C27, C28, C29, C30 | C1210 | 4 | CL32B106KBJNNNE | C138687
C53 | 0805 | 1 | 220nF
D1, D4 | SOT-23-3_L2.9-W1.3-P0.95-LS2.4-BR | 2 | SM05.TCT | C85197
D3, D6, D7, D8 | SMA_L4.4-W2.8-LS5.4-R-RD | 4 | SS54_C22452 | C22452
D5 | SMA_L4.3-W2.6-LS5.1-RD | 1 | B330A | C52037930
DC1 | DC-IN-TH_DC-470-2.1GP | 1 | DC-470-2.1GP | C194407
DC_BOOST_1 | HDR-TH_4P-P2.54-V-M | 1 | PZ254V-11-04P_C2691448 | C2691448
GND1 | PinHeader_1x01_P2.00mm_Vertical | 1 | PH_GND
GND2 | TestPoint_Pad_2.5x2.5mm | 1 | GND
H2_2, H5 | HDR-TH_20P-P2.54-V-M-R2-C10-S2.54 | 2 | 2.54-2*10 | C5116480
H5.1, H5.2 | HDR-TH_16P-P2.54-V-M_2 | 2 | HX PZ2.54-1X16P ZZ | C42372508
H7.1, H7.2, H7.3, H7.4 |  | 4
INB1 | PinHeader_1x01_P2.00mm_Vertical | 1 | INB1
INB2 | PinHeader_1x01_P2.00mm_Vertical | 1 | INB2
J1 | MPU6050_Module | 1 | Conn_01x08_Pin
J2 | PinHeader_1x03_P2.54mm_Vertical | 1 | Conn_01x03_Pin
L2 | IND-SMD_L8.5-W8.0_PCC-M0854M | 1 | PSPMAA0805-101M-ANP | C2962892
L4 | IND-SMD_L12.3-W12.3_SMDRI127 | 1 | SMDRI127-220MT | C9905
M_N1 | PinHeader_1x01_P2.00mm_Vertical | 1 | M_N
M_P1 | PinHeader_1x01_P2.00mm_Vertical | 1 | TestPoint
PWM1 | PinHeader_1x01_P2.00mm_Vertical | 1 | PWM
Q1 | SOP-8_L5.0-W3.8-P1.27-LS6.0-BL | 1 | AO4435_C2944310 | C2944310
Q14, Q16 | SOT-23-3_L2.9-W1.3-P1.90-LS2.4-TR | 2 | 2n3904S-RTK/PS_C18536 | C18536
R1 | RES-ADJ-SMD_3P-L3.0-W3.8-P1.75-BR | 1 | TC33X-2-103E | C719176
R11, R12, R24, R26, R29, R31, R35, R42, R43 | 0805 | 9 | 10k
R13 | R2512 | 1 | YLRY12-3-60F | C22468068
R14, R15, R17, R22 | 0805 | 4 | 2.2k
R16 | R0805 | 1 | RC0805FR-07390KL | C137535
R23, R79, R80 | 0805 | 3 | 1k
R25 | 0805 | 1 | 120
R27 | 0805 | 1 | 41.2K | C2077335
R28, R32, R33, R34, R37, R38 | 0805 | 6 | 4.7K
R30, R39, R41 | 0805 | 3 | 100K
R36 | 0805 | 1 | 30k
R40 | 0805 | 1 | 6.8k
R81, R82 | 0805 | 2 | 0
R84, R85 | 0805 | 2 | 1M
SW2 | SW-SMD_4P-L6.0-W6.0-P4.50-LS8.2 | 1 | BOOT | C7528752
SW4 | SW-SMD_4P-L6.0-W6.0-P4.50-LS8.2 | 1 | RESET | C7528752
TP1 | TestPoint_THTPad_D4.0mm_Drill2.0mm | 1 | TDS_1
TP2 | TestPoint_THTPad_D4.0mm_Drill2.0mm | 1 | TDS_2
U1 | SOT-23-5_L3.0-W1.7-P0.95-LS2.8-BL | 1 | SY6280AAC | C55136
U10, U11, U8, U9 | CONN-TH_2P-P3.81_DB125-3.81-2P-BK-S | 4 | DB125-3.81-2P-BK-S | C430618
U15 | SOIC-16_3.9x9.9mm_P1.27mm | 1 | CH340C
U16 | ESP32-WROOM-32U | 1 | ESP32-WROOM-32D
U2 | L298N-module-43x43mm | 1 | L298N
U3 | ESSOP-10_L4.9-W3.9-P1.0-LS6.0-TL-EP | 1 | CH224K | C970725
U4 | SSOP-10_L4.9-W3.9-P1.00-LS6.0-BL | 1 | CN3795 | C150555
U5 | SOIC-8_L5.0-W4.0-P1.27-LS6.0-BL | 1 | LM358DR | C5423
U7 | PG-TO-263-5_L10.2-W8.7-P1.70-LS14.4-BR | 1 | LM2576HVS-3.3 | C347436
USB1 | USB-C-SMD_TYPE-C-16PIN-2MD-073 | 1 | TYPE-C 16PIN 2MD | C2765186
VCC1 | PinHeader_1x01_P2.00mm_Vertical | 1 | M_VCC

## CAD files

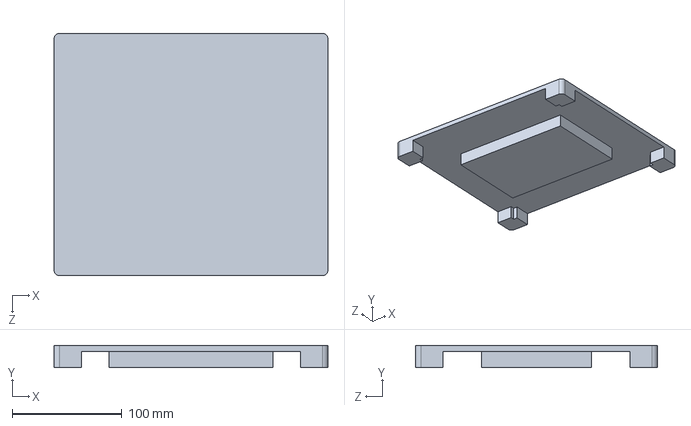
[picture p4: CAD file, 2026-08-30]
3D DESIGN/base para ambú.SLDPRT
250.0 x 20.5 x 221.0 mm

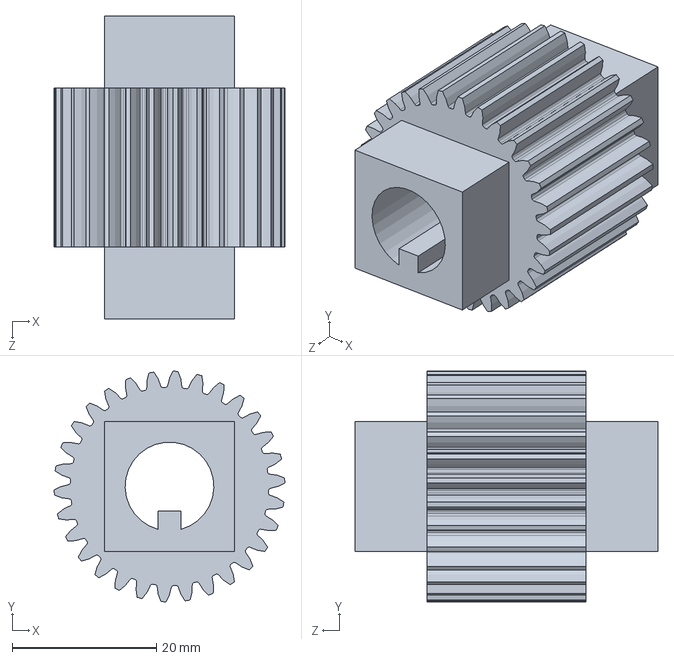
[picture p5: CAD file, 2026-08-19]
MANUFACTURING/prueba de engranaje real.SLDPRT
32.0 x 32.0 x 42.0 mm

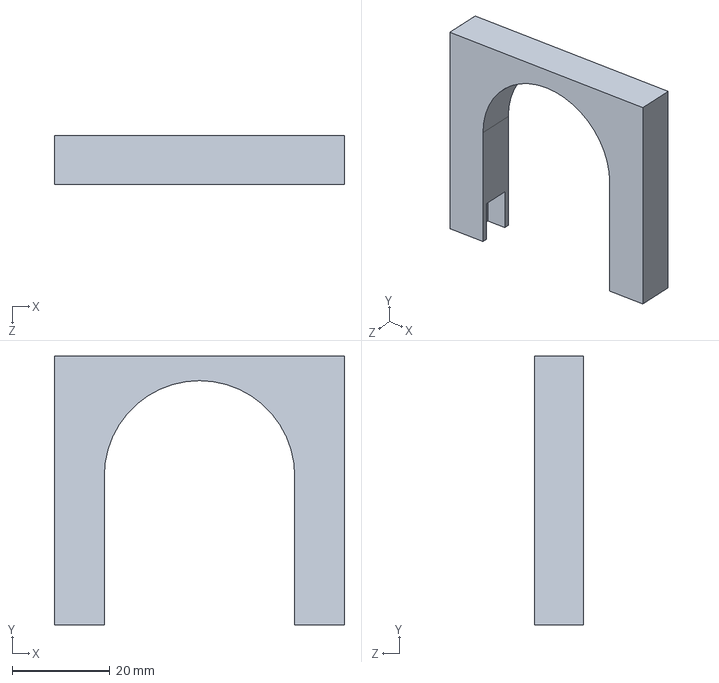
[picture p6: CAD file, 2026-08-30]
3D DESIGN/soporte circunferencia pequeña ambu.SLDPRT
59.4 x 55.0 x 10.0 mm

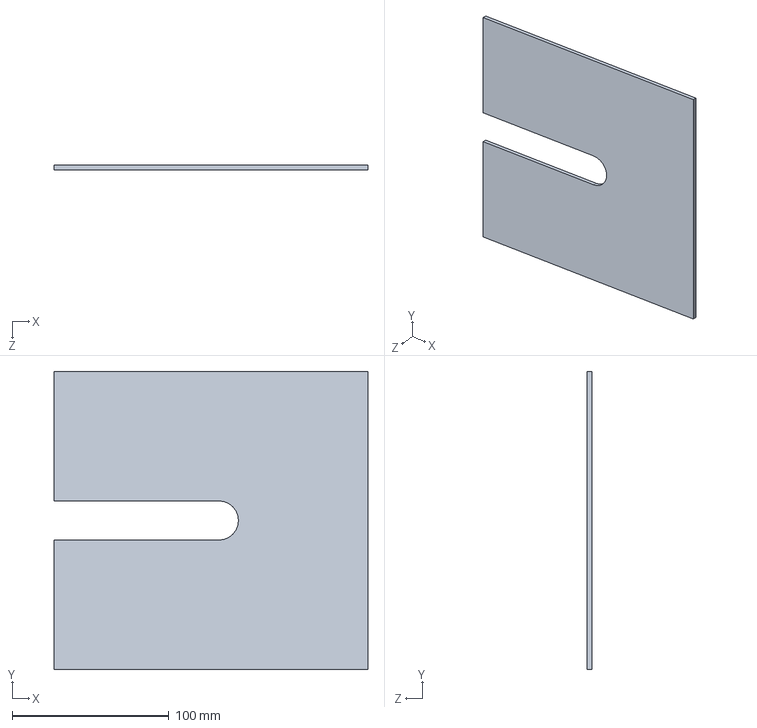
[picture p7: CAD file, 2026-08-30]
3D DESIGN/panel acrilico 2.SLDPRT
200.0 x 190.0 x 3.00 mm

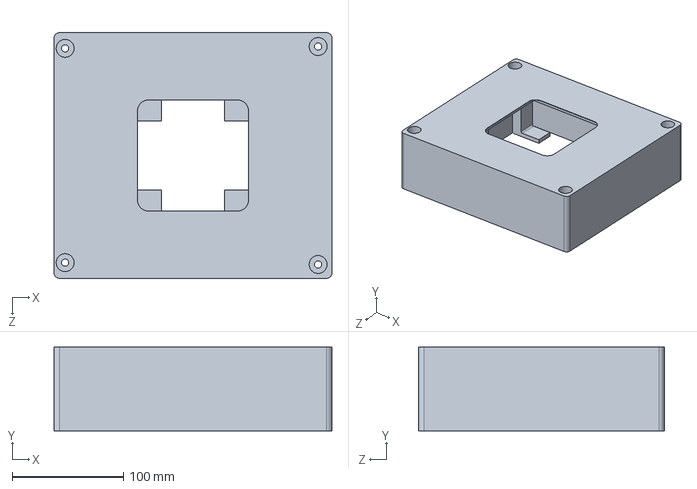
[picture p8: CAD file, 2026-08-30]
3D DESIGN/Tapa_Superior_AMBU.SLDPRT
250.0 x 75.5 x 221.0 mm

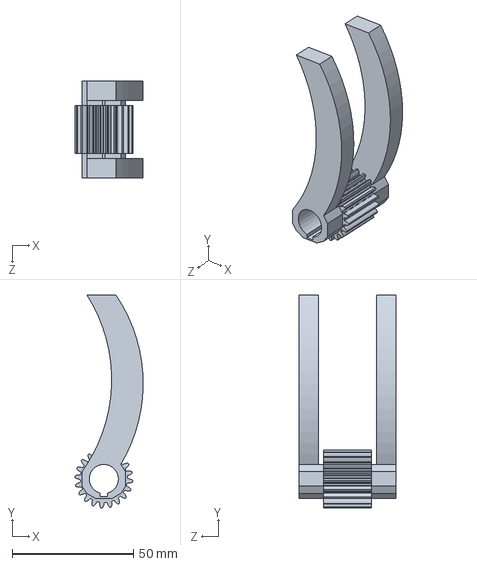
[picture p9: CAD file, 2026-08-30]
3D DESIGN/engranaje_con_brazo - copia.SLDPRT
28.2 x 88.0 x 40.0 mm

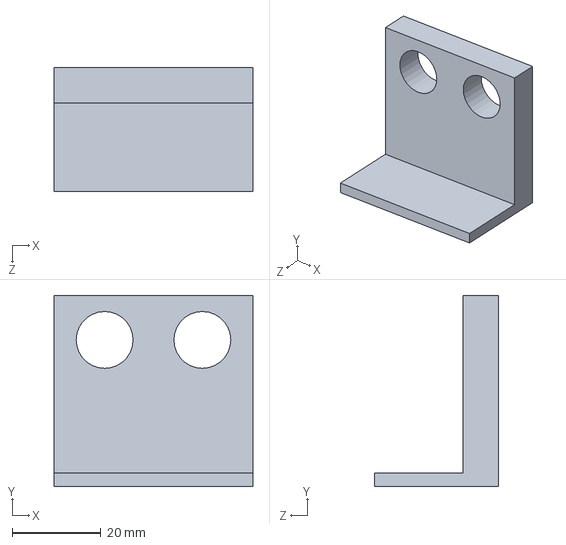
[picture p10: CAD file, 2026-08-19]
3D DESIGN/soporte ambu nuevo.SLDPRT
44.8 x 43.0 x 28.0 mm

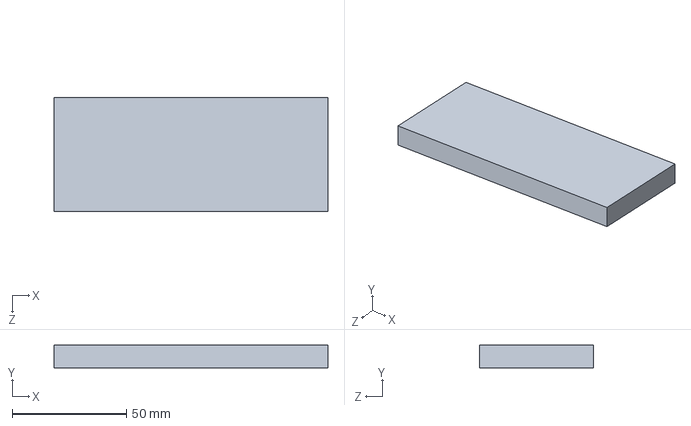
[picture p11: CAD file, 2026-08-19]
3D DESIGN/elevador de ejes.SLDPRT
120.0 x 10.0 x 50.0 mm

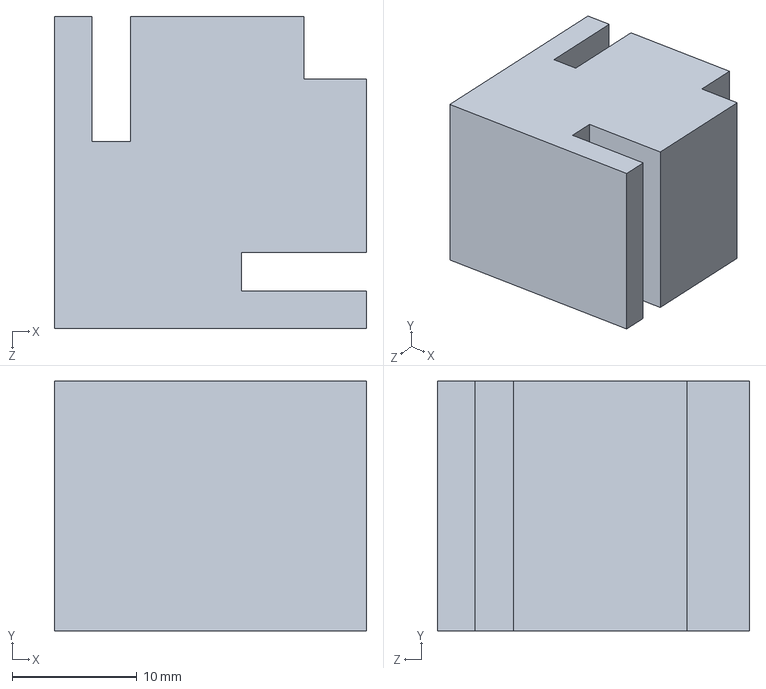
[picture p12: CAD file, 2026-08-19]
3D DESIGN/agarradera de acrilico.SLDPRT
25.0 x 20.0 x 25.0 mm

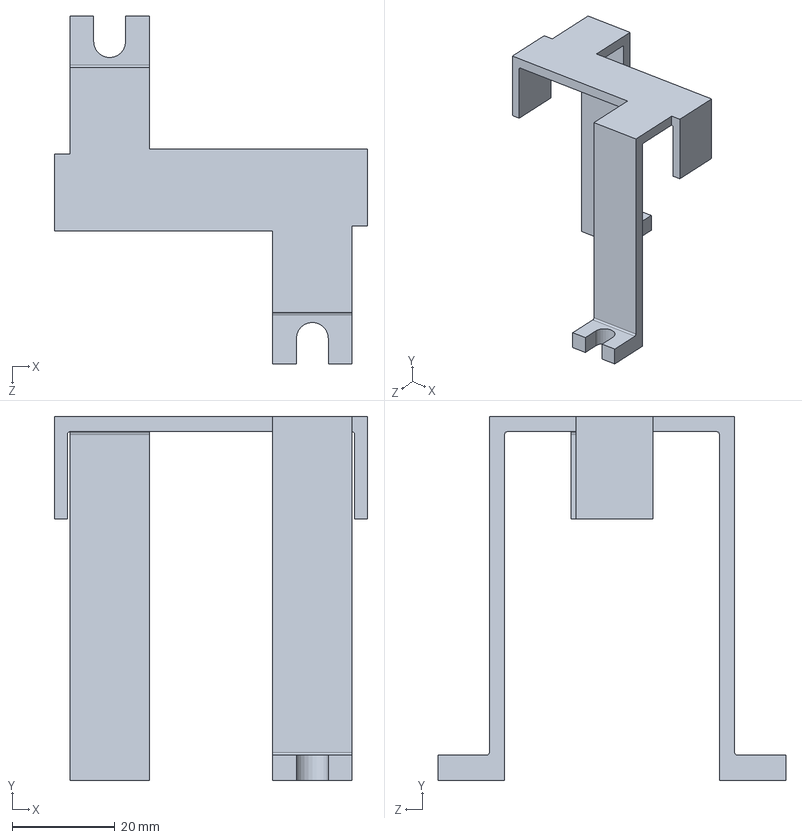
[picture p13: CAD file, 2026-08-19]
3D DESIGN/soporte para bateria ambu revisado.SLDPRT
61.0 x 71.0 x 67.8 mm

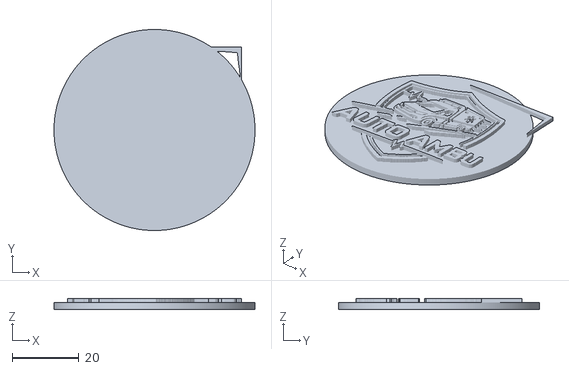
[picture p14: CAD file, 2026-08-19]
3D DESIGN/AUTO_AMBU_60mm_alta_resolucion_base_logo.stl
60.0 x 60.0 x 3.20

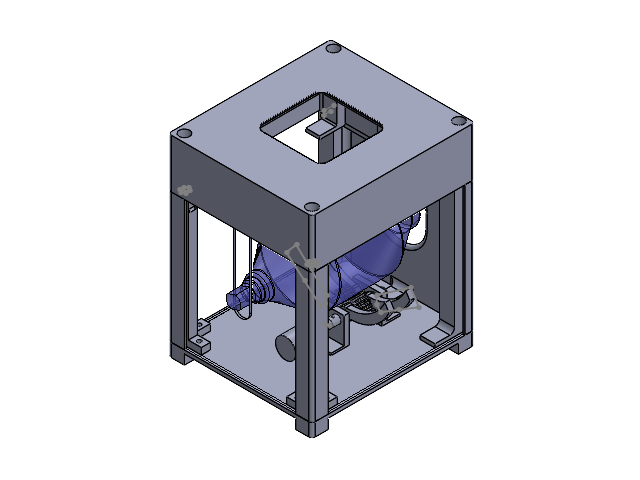
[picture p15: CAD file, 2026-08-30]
3D DESIGN/Ensamblaje_ambu_nuevo.SLDASM
Eje mecanizado x 2
soporte ambu nuevo x 2
engranaje_con_brazo - copia x 2
cuña
bolsa ambu
pared trasera
base para ambú
agarradera de acrilico1 x 2
panel de acrilico ambú x 4
panel acrilico 2
acople motor 2 a nuevo ambu
motor 2
Tapa_Superior_AMBU

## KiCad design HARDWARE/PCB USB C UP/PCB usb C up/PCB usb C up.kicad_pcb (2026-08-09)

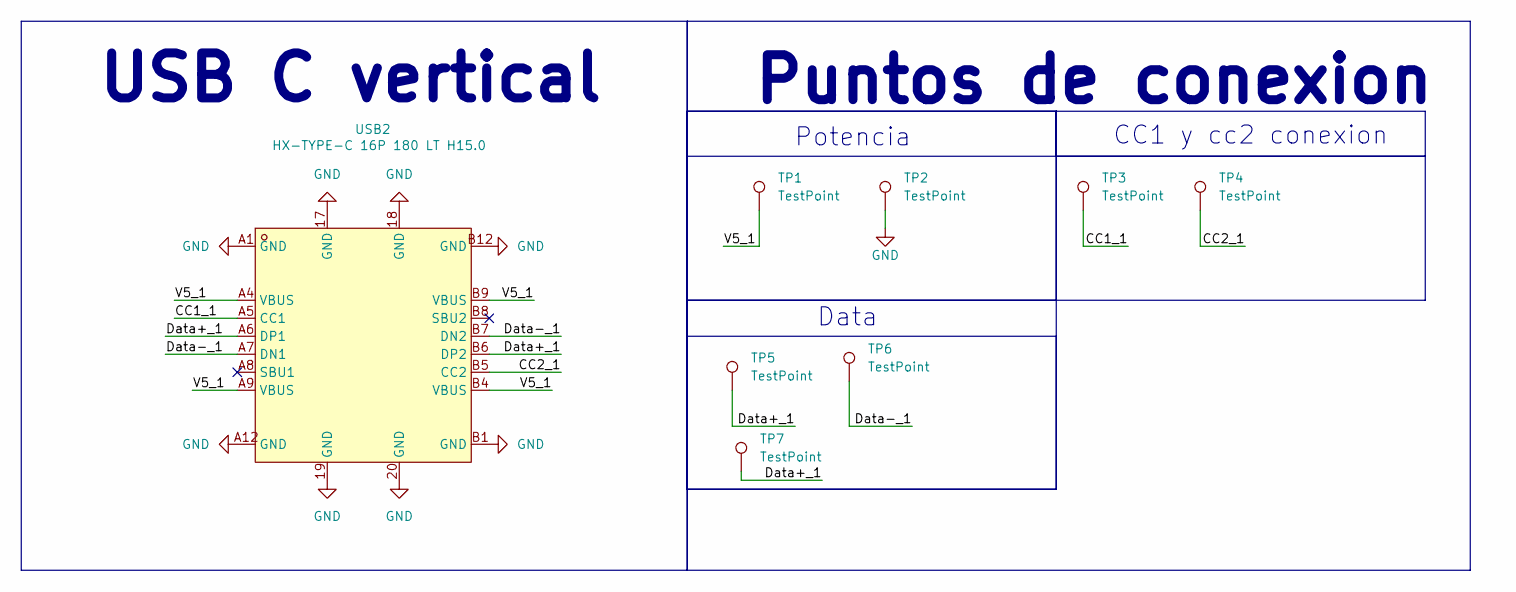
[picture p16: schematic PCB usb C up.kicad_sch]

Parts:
TP1, TP2, TP3, TP4, TP5, TP6, TP7: TestPoint; TestPoint_THTPad_2.0x2.0mm_Drill1.0mm
USB2: HX-TYPE-C 16P 180 LT H15.0; USB-C-SMD_HX-TYPE-C-16P-180-LT-H15.0; LCSC Part C49261573

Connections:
/CC1_1: TP3.1 (1_1), USB2.A5 (CC1)
/CC2_1: TP4.1 (1_1), USB2.B5 (CC2)
/Data+_1: TP5.1 (1_1), TP7.1 (1_1), USB2.A6 (DP1), USB2.B6 (DP2)
/Data-_1: TP6.1 (1_1), USB2.A7 (DN1), USB2.B7 (DN2)
/V5_1: TP1.1 (1_1), USB2.A4 (VBUS), USB2.A9 (VBUS), USB2.B4 (VBUS), USB2.B9 (VBUS)
GND: TP2.1 (1_1), USB2.17 (GND), USB2.18 (GND), USB2.19 (GND), USB2.20 (GND), USB2.A1 (GND), USB2.A12 (GND), USB2.B1 (GND), USB2.B12 (GND)

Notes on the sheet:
Potencia
USB C vertical
Data
CC1 y cc2 conexion
Puntos de conexion

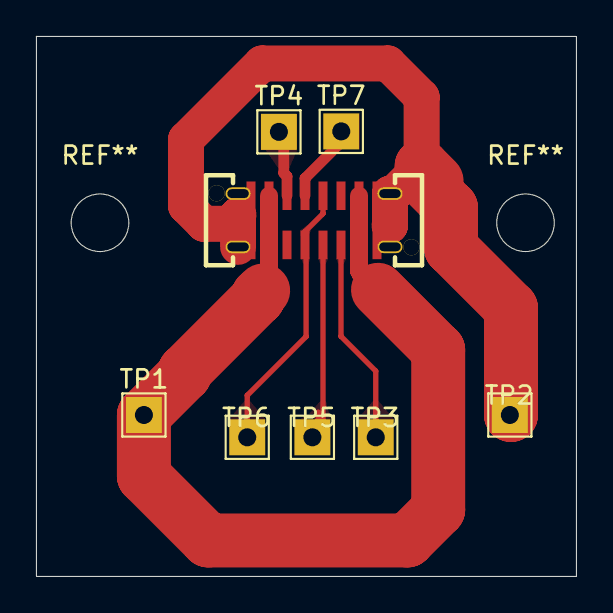
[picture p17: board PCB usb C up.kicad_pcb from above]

Board: 2 copper layers, 30.0 x 30.0 mm, 8 parts (0 on the bottom side), 6 nets.

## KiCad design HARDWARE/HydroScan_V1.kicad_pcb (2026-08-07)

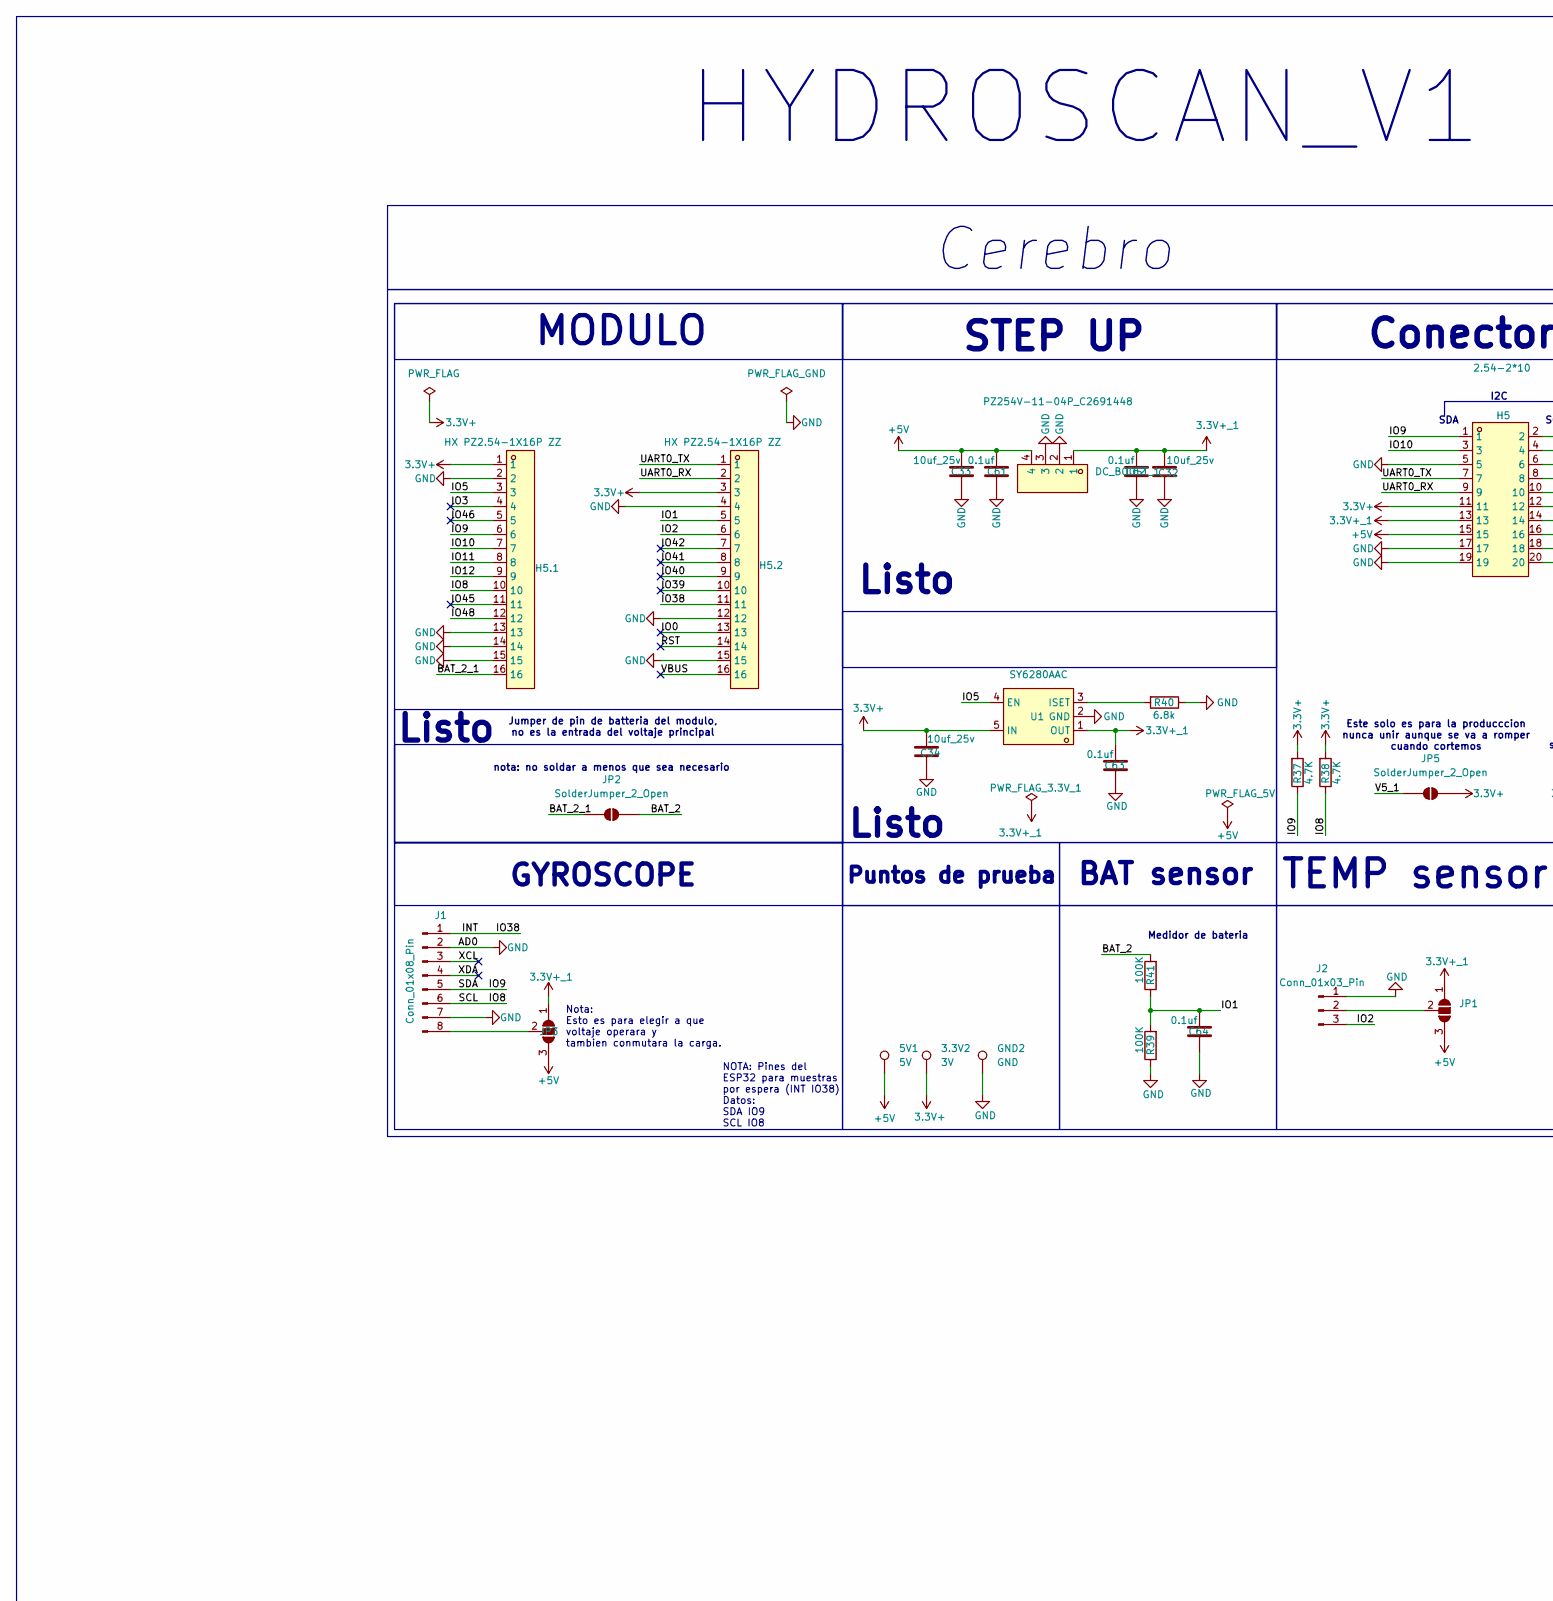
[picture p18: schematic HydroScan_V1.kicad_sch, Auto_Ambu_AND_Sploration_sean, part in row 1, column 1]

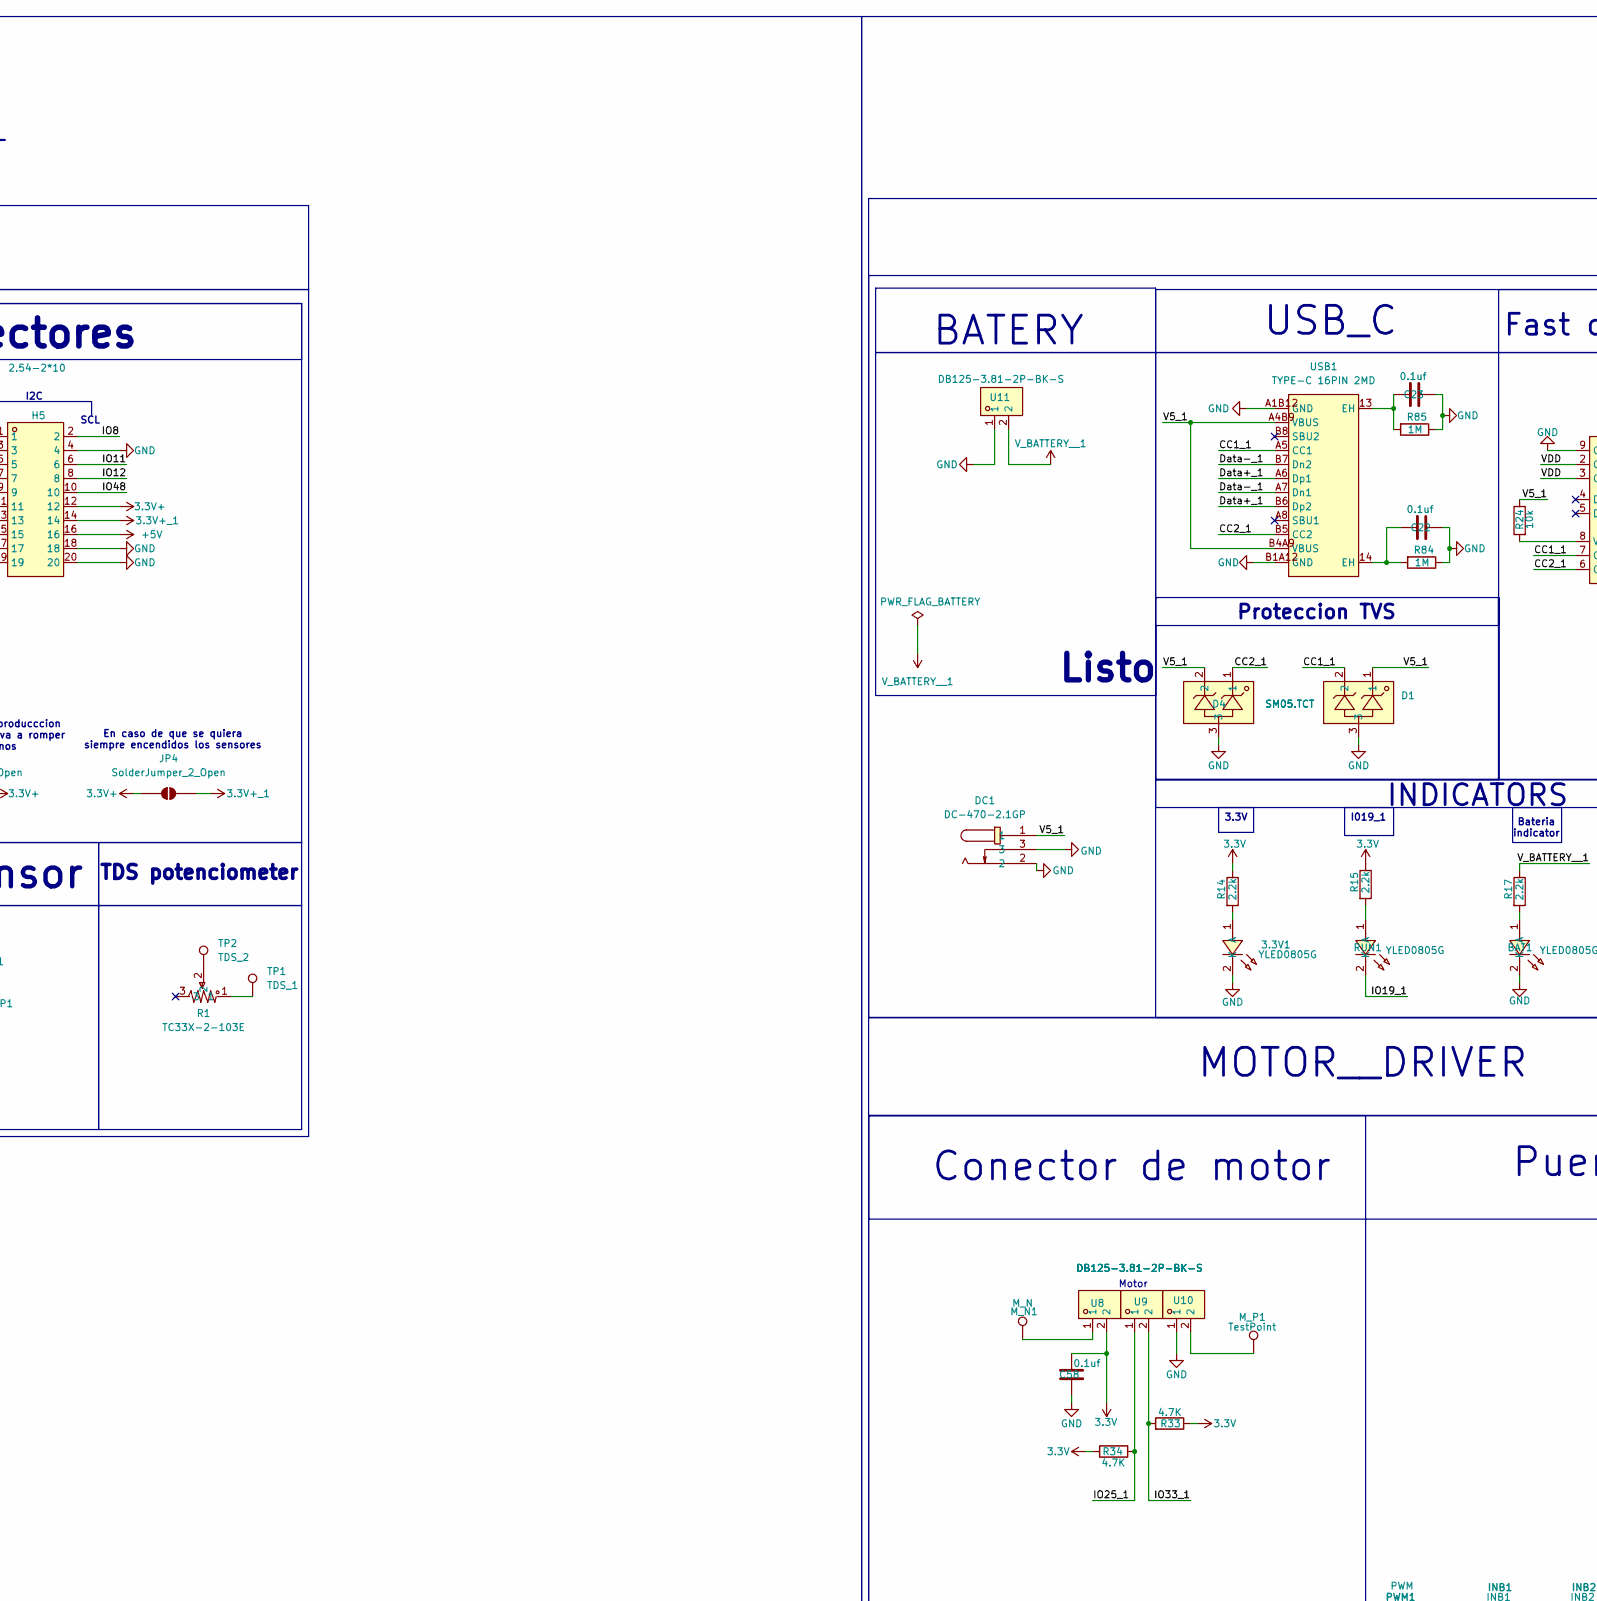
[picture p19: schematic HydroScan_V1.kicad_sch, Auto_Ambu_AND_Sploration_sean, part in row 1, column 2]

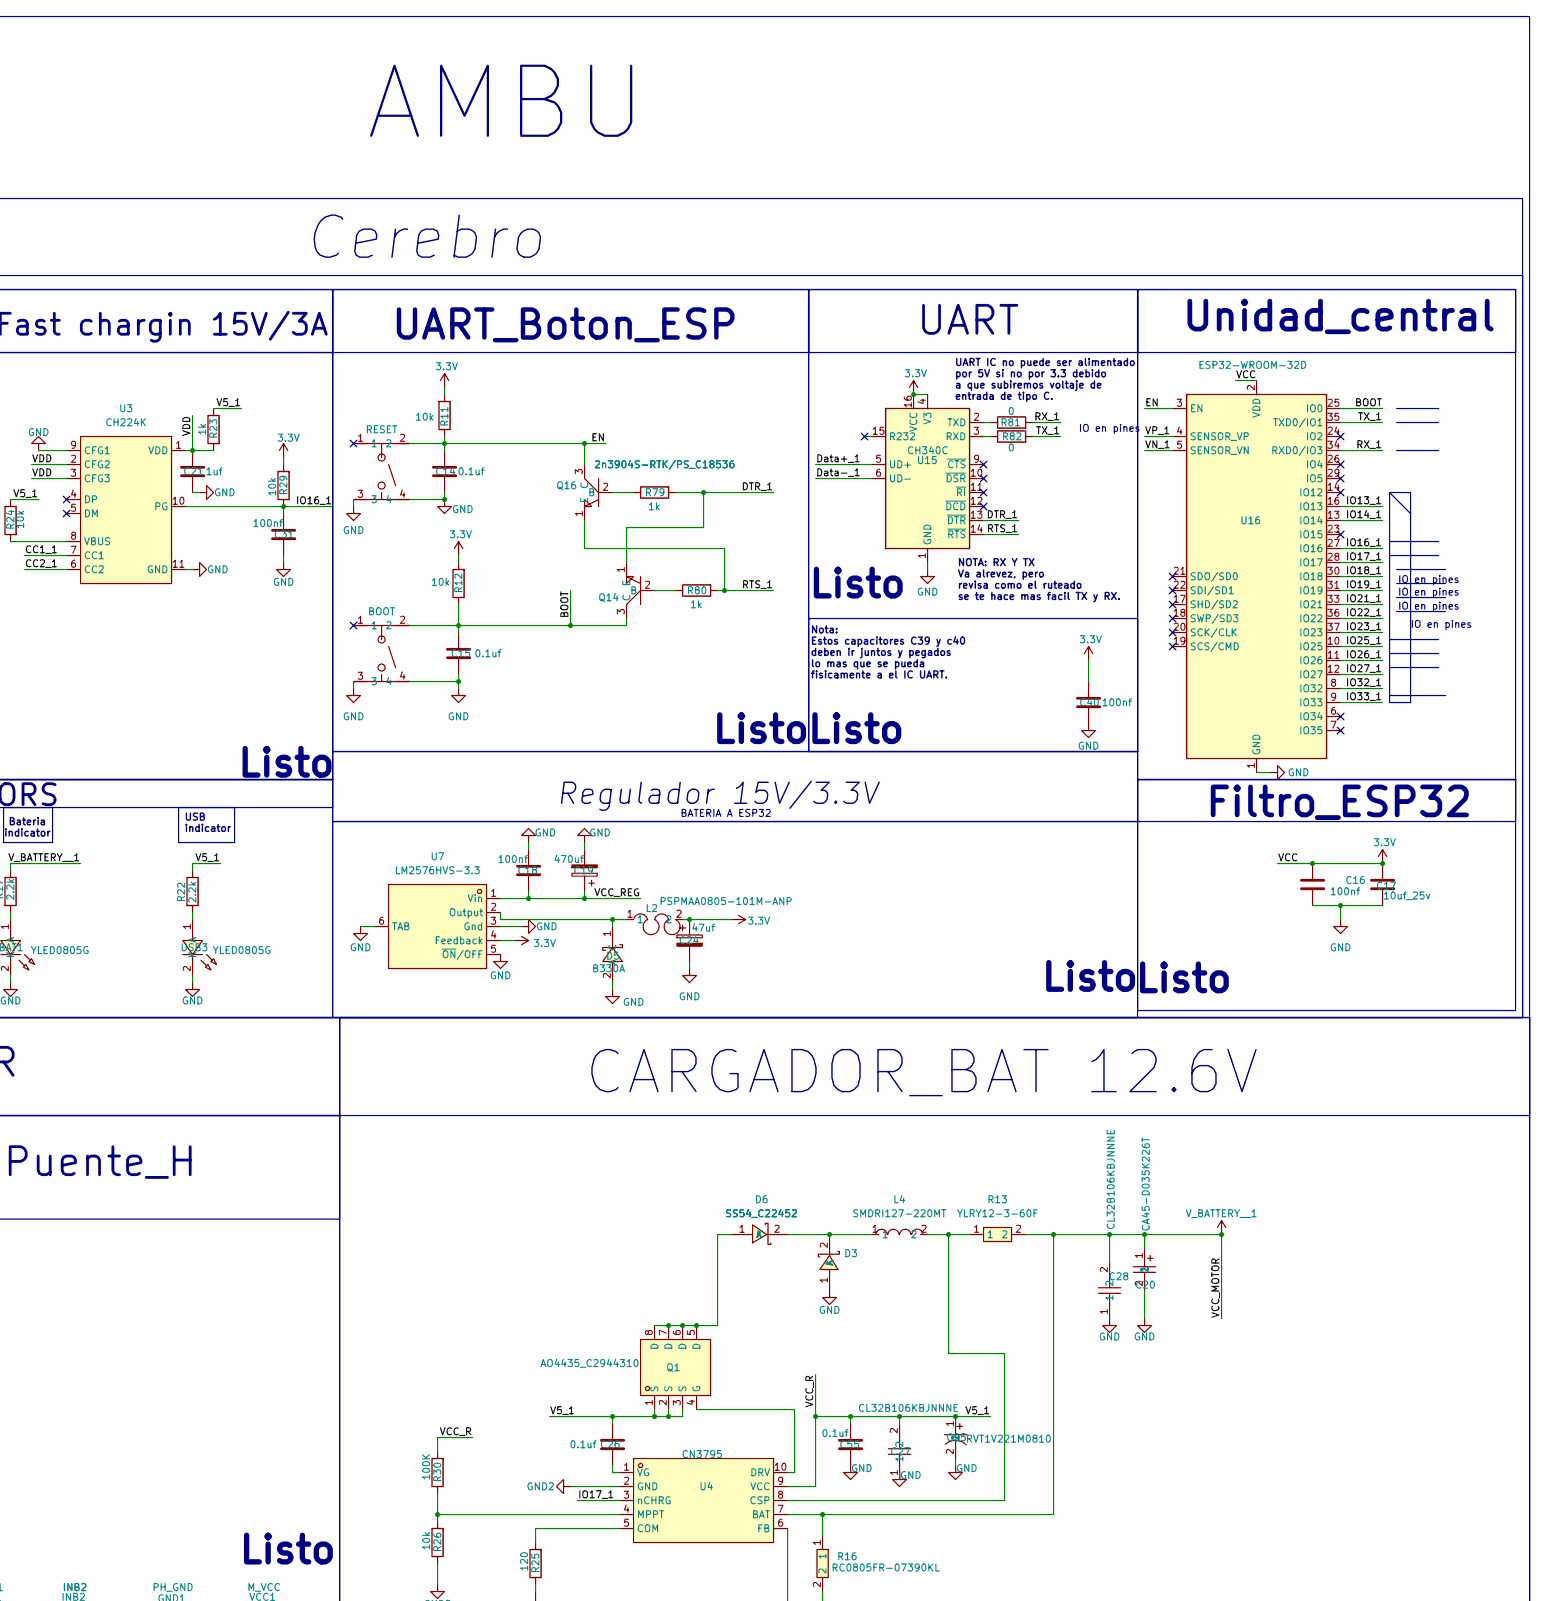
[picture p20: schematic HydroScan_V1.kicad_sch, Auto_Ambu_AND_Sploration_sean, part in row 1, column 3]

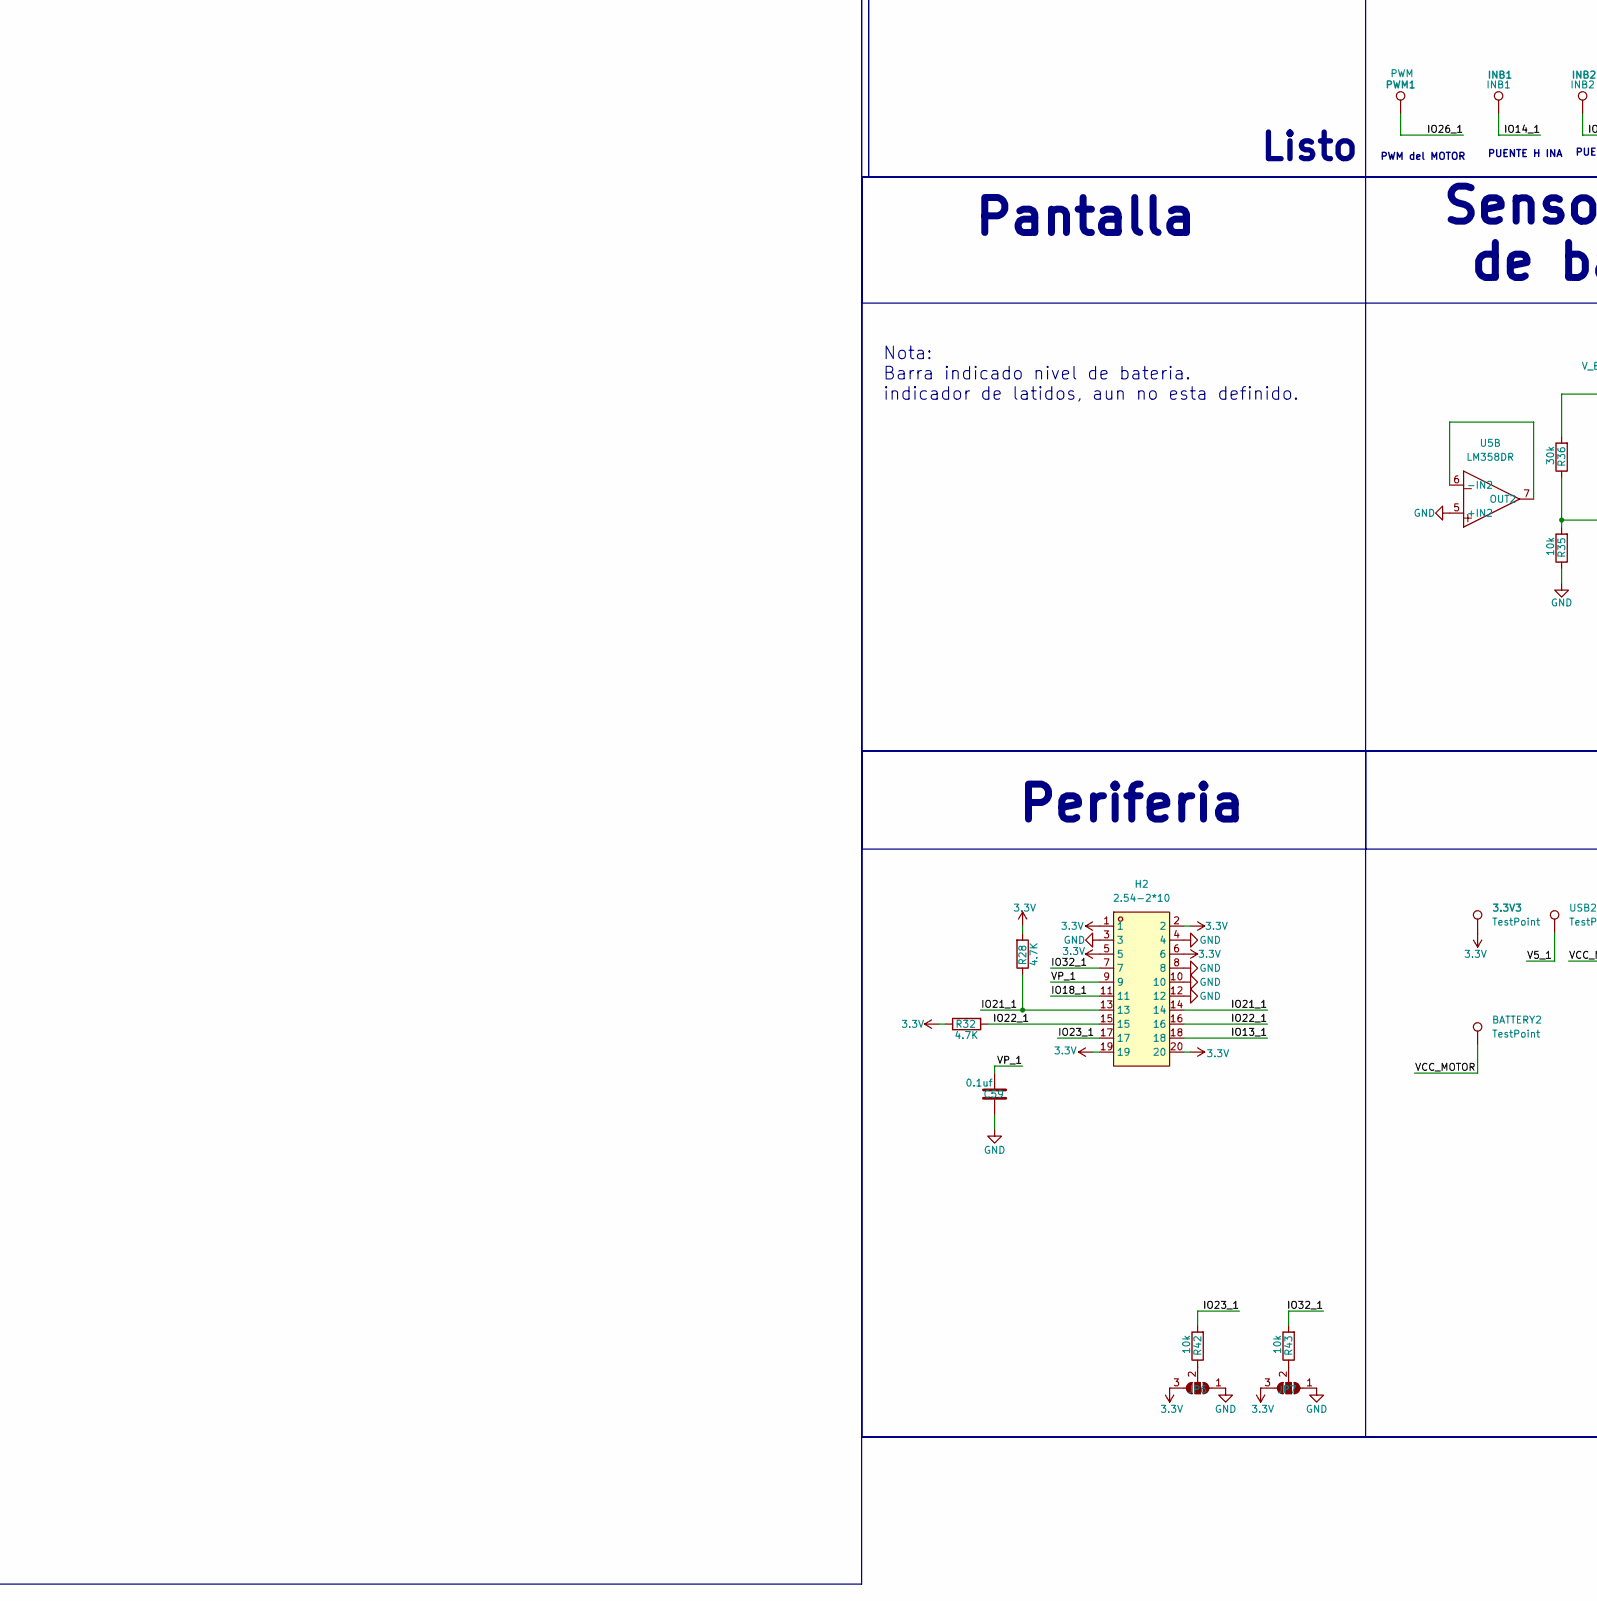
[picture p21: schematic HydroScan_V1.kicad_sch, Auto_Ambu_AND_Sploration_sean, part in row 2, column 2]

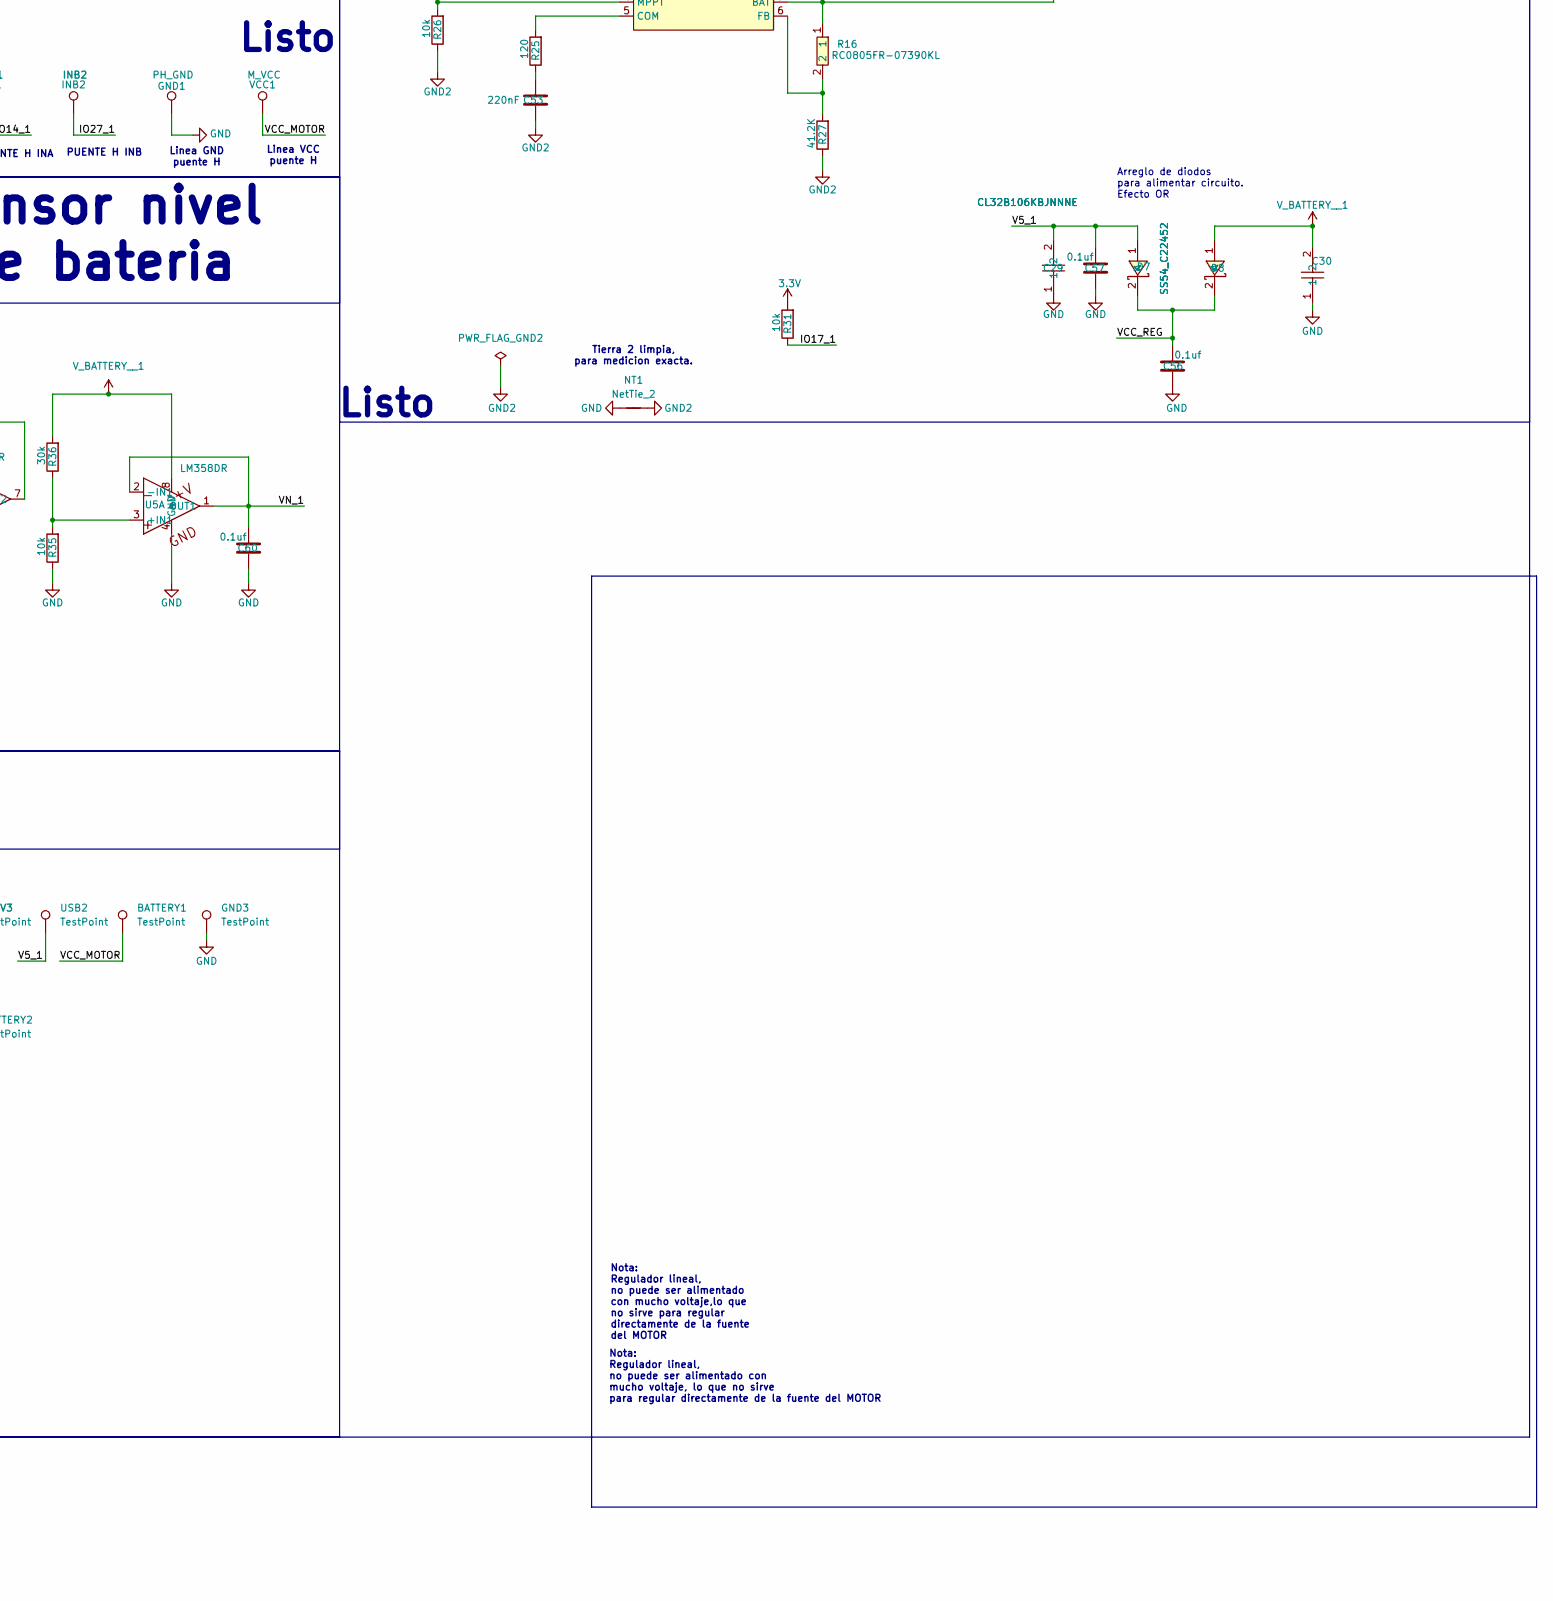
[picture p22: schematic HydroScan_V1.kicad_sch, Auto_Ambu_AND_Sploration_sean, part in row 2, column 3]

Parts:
3.3V1: YLED0805G; LED0805-FD-GREEN; MPN YLED0805G; LCSC Part C25170728
3.3V2: 3V; TestPoint_Pad_2.5x2.5mm
3.3V3: TestPoint; TestPoint_Pad_2.0x2.0mm
5V1: 5V; TestPoint_Pad_2.5x2.5mm
BAT1: YLED0805G; LED0805-FD-GREEN; MPN YLED0805G; LCSC Part C25170728
BATTERY1, BATTERY2: TestPoint; TestPoint_Pad_2.0x2.0mm
C14, C15, C22, C23, C26, C55, C56, C57, C58, C59, C60, C61, C62, C63, C64: 0.1uf; C_0805_2012Metric_Pad1.18x1.45mm_HandSolder
C16, C18, C31, C40: 100nf; C_0805_2012Metric_Pad1.18x1.45mm_HandSolder
C17, C32, C33, C34: 10uf_25v; C_0805_2012Metric_Pad1.18x1.45mm_HandSolder
C19: 470uf; C_Elec_10x10.2; LCSC C72518
C20: CA45-D035K226T; CAP-SMD_L7.3-W4.3-R-RD; MPN CA45-D035K226T; LCSC Part C126947
C21: 1uf; C_0805_2012Metric_Pad1.18x1.45mm_HandSolder
C24: 47uf; C_Elec_6.3x7.7; LCSC C72523
C25: RVT1V221M0810; CAP-SMD_BD8.0-L8.3-W8.3-LS9.1-FD; MPN RVT1V221M0810; LCSC Part C3340
C27, C28, C29, C30: CL32B106KBJNNNE; C1210; MPN CL32B106KBJNNNE; LCSC Part C138687
C53: 220nF; C_0805_2012Metric_Pad1.18x1.45mm_HandSolder
D1, D4: SM05.TCT; SOT-23-3_L2.9-W1.3-P0.95-LS2.4-BR; MPN SM05.TCT; LCSC Part C85197
D3, D6, D7, D8: SS54_C22452; SMA_L4.4-W2.8-LS5.4-R-RD; MPN SS54; LCSC Part C22452
D5: B330A; SMA_L4.3-W2.6-LS5.1-RD; MPN B330A; LCSC Part C52037930
DC1: DC-470-2.1GP; DC-IN-TH_DC-470-2.1GP; MPN DC-470-2.1GP; LCSC Part C194407
DC_BOOST_1: PZ254V-11-04P_C2691448; HDR-TH_4P-P2.54-V-M; MPN PZ254V-11-04P; LCSC Part C2691448
GND1: PH_GND; PinHeader_1x01_P2.00mm_Vertical
GND2: GND; TestPoint_Pad_2.5x2.5mm
GND3: TestPoint; TestPoint_Pad_2.0x2.0mm
H2, H5: 2.54-2*10; HDR-TH_20P-P2.54-V-M-R2-C10-S2.54; MPN 2.54-2*10; LCSC Part C5116480
H5.1, H5.2: HX PZ2.54-1X16P ZZ; HDR-TH_16P-P2.54-V-M_2; MPN HX PZ2.54-1x16P ZZ; LCSC Part C42372508
INB1: INB1; PinHeader_1x01_P2.00mm_Vertical
INB2: INB2; PinHeader_1x01_P2.00mm_Vertical
J1: Conn_01x08_Pin; MPU6050_Module
J2: Conn_01x03_Pin; PinHeader_1x03_P2.54mm_Vertical
JP1, JP3, JP6, JP7: SolderJumper_3_Open; SolderJumper-3_P1.3mm_Open_RoundedPad1.0x1.5mm_NumberLabels
JP2, JP4, JP5: SolderJumper_2_Open; SolderJumper-2_P1.3mm_Open_Pad1.0x1.5mm
L2: PSPMAA0805-101M-ANP; IND-SMD_L8.5-W8.0_PCC-M0854M; LCSC Part C2962892
L4: SMDRI127-220MT; IND-SMD_L12.3-W12.3_SMDRI127; MPN SMDRI127-220MT; LCSC Part C9905
M_N1: M_N; PinHeader_1x01_P2.00mm_Vertical
M_P1: TestPoint; PinHeader_1x01_P2.00mm_Vertical
NT1: NetTie_2; NetTie-2_SMD_Pad0.5mm
PWM1: PWM; PinHeader_1x01_P2.00mm_Vertical
Q1: AO4435_C2944310; SOP-8_L5.0-W3.8-P1.27-LS6.0-BL; MPN AO4435; LCSC Part C2944310
Q14, Q16: 2n3904S-RTK/PS_C18536; SOT-23-3_L2.9-W1.3-P1.90-LS2.4-TR; LCSC Part C18536
R1: TC33X-2-103E; RES-ADJ-SMD_3P-L3.0-W3.8-P1.75-BR; MPN TC33X-2-103E; LCSC Part C719176
R11, R12, R26, R29, R31, R35, R42, R43: 10k; R_0805_2012Metric_Pad1.20x1.40mm_HandSolder
R13: YLRY12-3-60F; R2512; MPN YLRY12-3-60F; LCSC Part C22468068
R14, R15, R17, R22: 2.2k; R_0805_2012Metric_Pad1.20x1.40mm_HandSolder
R16: RC0805FR-07390KL; R0805; MPN RC0805FR-07390KL; LCSC Part C137535
R23, R79, R80: 1k; R_0805_2012Metric_Pad1.20x1.40mm_HandSolder
R24: 10k; C_0805_2012Metric_Pad1.18x1.45mm_HandSolder
R25: 120; R_0805_2012Metric_Pad1.20x1.40mm_HandSolder
R27: 41.2K; R_0805_2012Metric_Pad1.20x1.40mm_HandSolder; LCSC C2077335
R28, R32, R33, R34, R37, R38: 4.7K; R_0805_2012Metric_Pad1.20x1.40mm_HandSolder
R30, R39, R41: 100K; R_0805_2012Metric_Pad1.20x1.40mm_HandSolder
R36: 30k; R_0805_2012Metric_Pad1.20x1.40mm_HandSolder
R40: 6.8k; R_0805_2012Metric_Pad1.20x1.40mm_HandSolder
R81, R82: 0; R_0805_2012Metric_Pad1.20x1.40mm_HandSolder
R84, R85: 1M; R_0805_2012Metric_Pad1.20x1.40mm_HandSolder
RUN1: YLED0805G; LED0805-FD-GREEN; MPN YLED0805G; LCSC Part C25170728
SW2: BOOT; SW-SMD_4P-L6.0-W6.0-P4.50-LS8.2; LCSC Part C7528752
SW4: RESET; SW-SMD_4P-L6.0-W6.0-P4.50-LS8.2; LCSC Part C7528752
TP1: TDS_1; TestPoint_THTPad_D4.0mm_Drill2.0mm
TP2: TDS_2; TestPoint_THTPad_D4.0mm_Drill2.0mm
U1: SY6280AAC; SOT-23-5_L3.0-W1.7-P0.95-LS2.8-BL; MPN SY6280AAC; LCSC Part C55136
U3: CH224K; ESSOP-10_L4.9-W3.9-P1.0-LS6.0-TL-EP; MPN CH224K; LCSC Part C970725
U4: CN3795; SSOP-10_L4.9-W3.9-P1.00-LS6.0-BL; MPN CN3795; LCSC Part C150555
U5: LM358DR; SOIC-8_L5.0-W4.0-P1.27-LS6.0-BL; MPN LM358DR; LCSC Part C5423
U7: LM2576HVS-3.3; PG-TO-263-5_L10.2-W8.7-P1.70-LS14.4-BR; LCSC Part C347436
U8, U9, U10, U11: DB125-3.81-2P-BK-S; CONN-TH_2P-P3.81_DB125-3.81-2P-BK-S; MPN DB125-3.81-2P-BK-S; LCSC Part C430618
U15: CH340C; SOIC-16_3.9x9.9mm_P1.27mm
U16: ESP32-WROOM-32D; ESP32-WROOM-32U
USB1: TYPE-C 16PIN 2MD; USB-C-SMD_TYPE-C-16PIN-2MD-073; MPN TYPE-C 16PIN 2MD(073); LCSC Part C2765186
USB2: TestPoint; TestPoint_Pad_2.0x2.0mm
USB3: YLED0805G; LED0805-FD-GREEN; MPN YLED0805G; LCSC Part C25170728
VCC1: M_VCC; PinHeader_1x01_P2.00mm_Vertical

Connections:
3.3V: 3.3V3.1 (1_1), C16.1, C17.1, C24.1, C40.1, C58.2, H2.1, H2.2, H2.5, H2.6, H2.19, H2.20, JP6.3 (B), JP7.3 (B), L2.2, R11.2, R12.2, R14.1, R15.1, R28.2, R29.2, R31.2, R32.1, R33.1, R34.1, U7.4 (Feedback), U8.2, U15.4 (V3), U15.16 (VCC), U16.2 (VDD)
3.3V+: 3.3V2.1 (1_1), C34.1, H5.11, H5.12, H5.1.1, H5.2.3, JP4.1 (A), JP5.2 (B), R37.2, R38.2, U1.5 (IN)
3.3V+_1: C32.1, C62.2, C63.2, DC_BOOST_1.1, H5.13, H5.14, JP1.1 (A), JP3.1 (A), JP4.2 (B), U1.1 (OUT)
+5V: 5V1.1 (1_1), C33.1, C61.2, DC_BOOST_1.4, H5.15, H5.16, JP1.3 (B), JP3.3 (B)
/BAT_2: JP2.2 (B), R41.2
/BAT_2_1: H5.1.16, JP2.1 (A)
/BOOT: C15.1, Q14.3 (C), R12.1, SW2.2, U16.25 (IO0)
/CC1_1: D1.2, U3.7 (CC1), USB1.A5 (CC1)
/CC2_1: D4.1, U3.6 (CC2), USB1.B5 (CC2)
/DTR_1: Q14.1 (E), R79.2, U15.13 (~DTR)
/Data+_1: U15.5 (UD+), USB1.A6 (Dp1), USB1.B6 (Dp2)
/Data-_1: U15.6 (UD-), USB1.A7 (Dn1), USB1.B7 (Dn2)
/EN: C14.1, Q16.3 (C), R11.1, SW4.2, U16.3 (EN)
/INT: H5.2.11, J1.1
/IO0: H5.2.13
/IO1: C64.2, H5.2.5, R39.2, R41.1
/IO2: H5.2.6, J2.3
/IO3: H5.1.4
/IO5: H5.1.3, U1.4 (EN)
/IO8: H5.2, H5.1.10, J1.6, R38.1
/IO9: H5.1, H5.1.6, J1.5, R37.1
/IO10: H5.3, H5.1.7
/IO11: H5.6, H5.1.8
/IO12: H5.8, H5.1.9
/IO13_1: H2.18, U16.16 (IO13)
/IO14_1: INB1.1 (1_1), U16.13 (IO14)
/IO16_1: C31.2, R29.1, U3.10 (PG), U16.27 (IO16)
/IO17_1: R31.1, U4.3 (nCHRG), U16.28 (IO17)
/IO18_1: H2.11, U16.30 (IO18)
/IO19_1: RUN1.2 (K), U16.31 (IO19)
/IO21_1: H2.13, H2.14, R28.1, U16.33 (IO21)
/IO22_1: H2.15, H2.16, R32.2, U16.36 (IO22)
/IO23_1: H2.17, R42.2, U16.37 (IO23)
/IO25_1: R34.2, U9.1, U16.10 (IO25)
/IO26_1: PWM1.1 (1_1), U16.11 (IO26)
/IO27_1: INB2.1 (1_1), U16.12 (IO27)
/IO32_1: H2.7, R43.2, U16.8 (IO32)
/IO33_1: R33.2, U9.2, U16.9 (IO33)
/IO39: H5.2.10
/IO40: H5.2.9
/IO41: H5.2.8
/IO42: H5.2.7
/IO45: H5.1.11
/IO46: H5.1.5
/IO48: H5.10, H5.1.12
/RST: H5.2.14
/RTS_1: Q16.1 (E), R80.2, U15.14 (~RTS)
/RX_1: R81.2, U16.34 (RXD0/IO3)
/TX_1: R82.2, U16.35 (TXD0/IO1)
/UART0_RX: H5.9, H5.2.2
/UART0_TX: H5.7, H5.2.1
/V5_1: C25.1, C26.2, C27.2, C29.2, C55.2, C57.2, D1.1, D4.2, D7.1 (A), DC1.1, JP5.1 (A), Q1.1 (S), Q1.2 (S), Q1.3 (S), R22.1, R23.1, R24.1, R30.2, U4.9 (VCC), USB1.A4B9 (VBUS), USB1.B4A9 (VBUS), USB2.1 (1_1)
/VBUS: H5.2.16
/VCC_REG: C18.1, C19.1, C56.2, D7.2 (K), D8.2 (K), U7.1 (Vin)
/VDD: C21.1, R23.2, U3.1 (VDD), U3.2 (CFG2), U3.3 (CFG3)
/VN_1: C60.2, U5.1 (OUT1), U5.2 (-IN1), U16.5 (SENSOR_VN)
/VP_1: C59.2, H2.9, U16.4 (SENSOR_VP)
/XCL: J1.3
/XDA: J1.4
GND: 3.3V1.2 (K), BAT1.2 (K), C14.2, C15.2, C16.2, C17.2, C18.2, C19.2, C20.2, C21.2, C22.2, C23.2, C24.2, C25.2, C27.1, C28.1, C29.1, C30.1, C31.1, C32.2, C33.2, C34.2, C40.2, C55.1, C56.1, C57.1, C58.1, C59.1, C60.1, C61.1, C62.1, C63.1, C64.1, D1.3, D3.1 (A), D4.3, D5.2 (A), DC1.2, DC1.3, DC_BOOST_1.2, DC_BOOST_1.3, GND1.1 (1_1), GND2.1 (1_1), GND3.1 (1_1), H2.3, H2.4, H2.8, H2.10, H2.12, H5.4, H5.5, H5.17, H5.18, H5.19, H5.20, H5.1.2, H5.1.13, H5.1.14, H5.1.15, H5.2.4, H5.2.12, H5.2.15, J1.2, J1.7, J2.1, JP6.1 (A), JP7.1 (A), NT1.1, R35.1, R39.1, R40.1, R84.1, R85.1, SW2.3, SW2.4, SW4.3, SW4.4, U1.2 (GND), U3.9 (CFG1), U3.11 (GND), U5.4 (GND), U5.5 (+IN2), U7.3 (Gnd), U7.5 (~ON/OFF), U7.6 (TAB), U10.1, U11.1, U15.1 (GND), U16.1 (GND), U16.15 (GND), U16.38 (GND), U16.39 (GND), USB1.A1B12 (GND), USB1.B1A12 (GND), USB3.2 (K); also elsewhere on the board
GND2: C53.1, NT1.2, R26.1, R27.1, U4.2 (GND)
unnamed: 3.3V1.1 (A), R14.2
unnamed: BAT1.1 (A), R17.2
unnamed: C22.1, R84.2, USB1.14 (EH)
unnamed: C23.1, R85.2, USB1.13 (EH)
unnamed: C53.2, R25.1
unnamed: D3.2 (K), D6.2 (K), L4.1
unnamed: D5.1 (C), L2.1, U7.2 (Output)
unnamed: D6.1 (A), Q1.5 (D), Q1.6 (D), Q1.7 (D), Q1.8 (D)
unnamed: J1.8, JP3.2 (C)
unnamed: J2.2, JP1.2 (C)
unnamed: JP6.2 (C), R42.1
unnamed: JP7.2 (C), R43.1
unnamed: M_N1.1 (1_1), U8.1
unnamed: M_P1.1 (1_1), U10.2
unnamed: Q1.4 (G), U4.10 (DRV)
unnamed: Q14.2 (B), R80.1
unnamed: Q16.2 (B), R79.1
unnamed: R1.1, TP1.1 (1_1)
unnamed: R1.2, TP2.1 (1_1)
unnamed: R15.2, RUN1.1 (A)
unnamed: R40.2, U1.3 (ISET)
unnamed: R24.2, U3.8 (VBUS)
unnamed: R25.2, U4.5 (COM)
unnamed: L4.2, R13.1, U4.8 (CSP)
unnamed: R16.2, R27.2, U4.6 (FB)
unnamed: R26.2, R30.1, U4.4 (MPPT)
unnamed: C26.1, U4.1 (VG)
unnamed: R35.2, R36.1, U5.3 (+IN1)
unnamed: U5.6 (-IN2), U5.7 (OUT2)
unnamed: R82.1, U15.3 (RXD)
unnamed: R81.1, U15.2 (TXD)
unnamed: R22.2, USB3.1 (A)
V_BATTERY__1: BATTERY1.1 (1_1), BATTERY2.1 (1_1), C20.1, C28.2, C30.2, D8.1 (A), R13.2, R16.1, R17.1, R36.2, U4.7 (BAT), U5.8 (+V), U11.2, VCC1.1 (1_1)

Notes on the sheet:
Periferia
MOTOR__DRIVER
NOTA: RX Y TX Va alrevez, pero revisa como el ruteado se te hace mas facil TX y RX.
IO en pines
Jumper de pin de batteria del modulo, no es la entrada del voltaje principal
Unidad_central
BATERY
Nota: Esto es para elegir a que voltaje operara y tambien conmutara la carga.
NOTA: Pines del ESP32 para muestras por espera (INT IO38) Datos: SDA IO9 SCL IO8
HYDROSCAN_V1
Linea GND puente H
Este solo es para la producccion nunca unir aunque se va a romper cuando cortemos
Nota: Regulador lineal, no puede ser alimentado con mucho voltaje, lo que no sirve para regular directamente de la fuente del MOTOR
Listo
Linea VCC puente H
Nota: Barra indicado nivel de bateria. indicador de latidos, aun no esta definido.
SCL
PWM del MOTOR
UART
Nota: Estos capacitores C39 y c40 deben ir juntos y pegados lo mas que se pueda fisicamente a el IC UART.
Fast chargin 15V/3A
STEP UP
Cerebro
Conectores
Puntos de prueba
PUENTE H INB
Nota: Regulador lineal, no puede ser alimentado con mucho voltaje,lo que no sirve para regular directamente de la fuente del MOTOR
nota: no soldar a menos que sea necesario
USB_C
Sensor nivel de bateria
CARGADOR_BAT 12.6V
I2C
Arreglo de diodos para alimentar circuito. Efecto OR
Filtro_ESP32
En caso de que se quiera siempre encendidos los sensores
Medidor de bateria
Pantalla
PUENTE H INA
BAT sensor
Motor

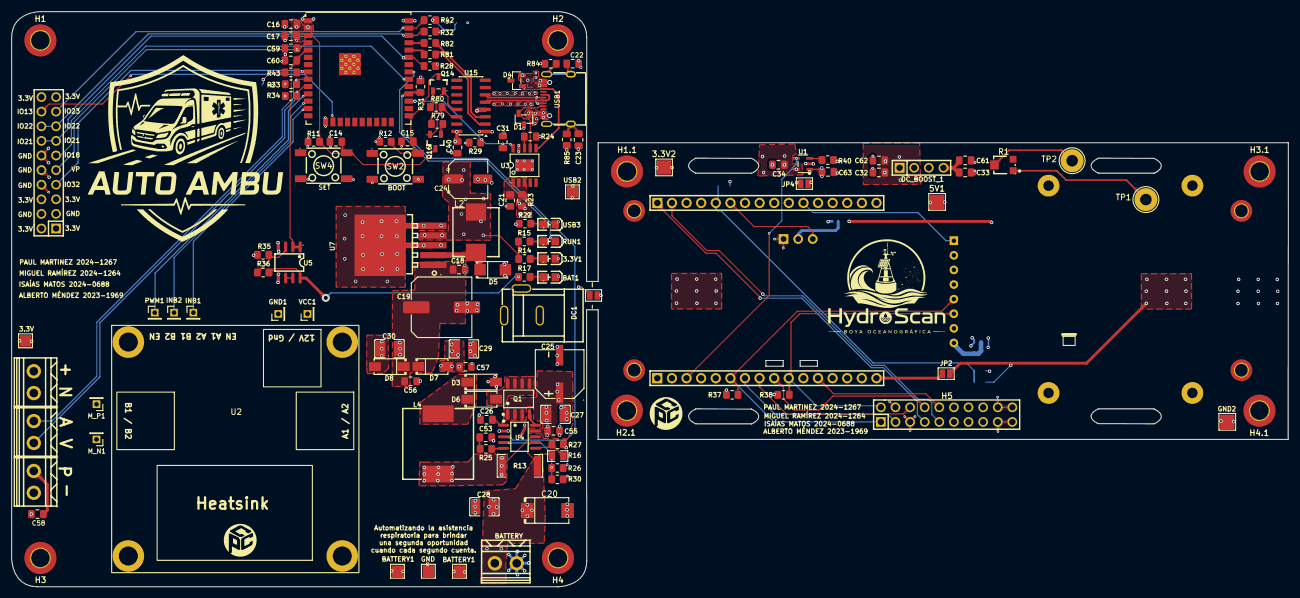
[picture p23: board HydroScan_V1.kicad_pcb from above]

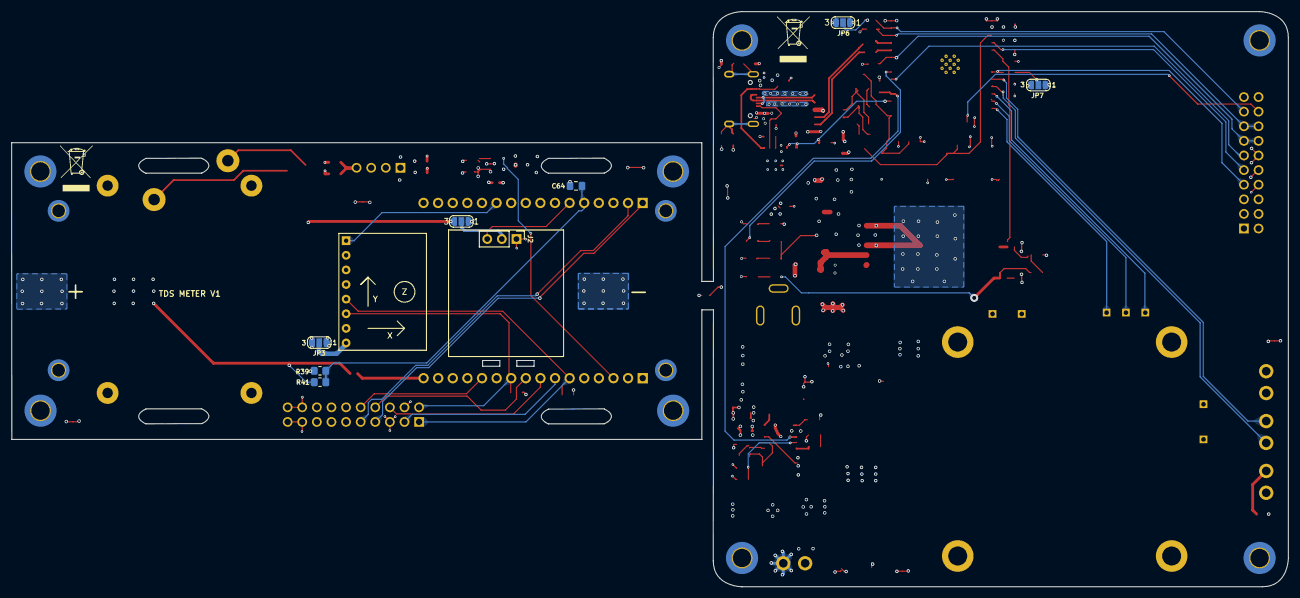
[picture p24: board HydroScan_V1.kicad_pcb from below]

Board: 4 copper layers, 222.0 x 100.0 mm, 153 parts (9 on the bottom side), 82 nets.

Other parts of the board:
1A: LOGO; 13
H1, H1.1, H2#2, H2.1, H3, H3.1, H4, H4.1: MountingHole_3.2mm_M3_DIN965_Pad_TopBottom
H7.1, H7.2, H7.3, H7.4: (no value)
H8.1, H8.2, H8.3, H8.4: MountingHole_2.2mm_M2_DIN965_Pad_TopBottom
THECPCENTER: LOGO; IMG1
THECPCENTER#2: LOGO; IMG1
U2: L298N; L298N-module-43x43mm
_: modulo esp32

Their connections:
GND: H7.1.1, H7.2.1, H7.3.1, H7.4.1, H8.1.1, H8.2.1, H8.3.1; also elsewhere on the board

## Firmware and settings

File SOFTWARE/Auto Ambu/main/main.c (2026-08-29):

// --------------------- AUTO AMBU ------------------------
//      Codigo v3.0
//
//      Maquina de estados
//      Sensor laser para posicion HOME
//
//      Selector:
//      OFF - INFANTE - ADULTO - AJUSTABLE - OFF
//
//      Selector activo LOW con pull-up
// --------------------------------------------------------

#include <stdio.h>
#include <stdbool.h>
#include <stdint.h>

#include "freertos/FreeRTOS.h"
#include "freertos/task.h"

#include "driver/gpio.h"
#include "driver/ledc.h"
#include "driver/adc.h"

#include "esp_log.h"

#include "board.h"


// ============================================================
// TAG
// ============================================================

static const char *TAG = "AUTO_AMBU";


// ============================================================
// CONFIGURACION PWM
// ============================================================

#define PWM_FREQUENCY_HZ       10000
#define PWM_RESOLUTION         LEDC_TIMER_10_BIT
#define PWM_MAX                1023


// ============================================================
// TIEMPOS DE DESCOMPRESION
// ============================================================

// Tiempo maximo permitido para que el sensor detecte HOME
// durante una descompresion normal.
#define TIEMPO_DESCOMPRESION_MAX_S       0.3f

// Tiempo maximo permitido para recuperar HOME durante
// el estado RECUPERACION_HOME.
#define TIEMPO_RECUPERACION_HOME_MAX_S   0.02f

// Tiempo maximo permitido para buscar HOME durante
// el arranque del sistema.
#define TIEMPO_INICIO_HOME_MAX_S         0.50f


// ============================================================
// TIEMPO DE COMPROBACION
// ============================================================

// Periodo de actualizacion de la maquina de estados.
#define ESTADO_TICK_MS                   10


// ============================================================
// ESTADOS DE LA MAQUINA
// ============================================================

typedef enum
{
    ESTADO_INICIO = 0,

    ESTADO_OFF,

    ESTADO_INFANTE,

    ESTADO_ADULTO,

    ESTADO_AJUSTABLE,

    ESTADO_RECUPERACION_HOME,

    ESTADO_ERROR

} estado_t;


// ============================================================
// VARIABLES GLOBALES
// ============================================================

static estado_t estado_actual = ESTADO_INICIO;


// ============================================================
// PROTOTIPOS
// ============================================================

// ---------------- Motor ----------------

static void motor_detener(void);

static void motor_comprimir(void);

static void motor_descomprimir(void);

static void motor_pwm_set(float porcentaje);


// ---------------- Selector ----------------

static void leer_selector(
    bool *adulto,
    bool *infante,
    bool *ajustable
);

static bool selector_off(void);

static bool selector_valido(void);


// ---------------- Sensores ----------------

static bool sensor_home(void);

static float leer_frecuencia_ajustable(void);

static float leer_voltaje_bateria(void);


// ---------------- Ciclo ----------------

static bool ejecutar_compresion(void);

static bool ejecutar_descompresion(void);

static bool ejecutar_ciclo(float frecuencia);


// ---------------- Estados ----------------

static void entrar_estado(estado_t nuevo_estado);

static bool buscar_home_inicio(void);


// ============================================================
// CONFIGURACION GPIO
// ============================================================

static void configurar_gpio(void)
{
    // --------------------------------------------------------
    // SELECTOR
    // Activo LOW + pull-up
    // --------------------------------------------------------

    gpio_config_t selector_config = {
        .pin_bit_mask =
            (1ULL << PIN_MODO_ADULTO) |
            (1ULL << PIN_MODO_NINO) |
            (1ULL << PIN_MODO_AJUSTABLE),

        .mode = GPIO_MODE_INPUT,

        .pull_up_en = GPIO_PULLUP_ENABLE,
        .pull_down_en = GPIO_PULLDOWN_DISABLE,

        .intr_type = GPIO_INTR_DISABLE
    };

    ESP_ERROR_CHECK(
        gpio_config(&selector_config)
    );


    // --------------------------------------------------------
    // PUENTE H
    // --------------------------------------------------------

    gpio_config_t motor_config = {
        .pin_bit_mask =
            (1ULL << PIN_MOTOR_INB1) |
            (1ULL << PIN_MOTOR_INB2),

        .mode = GPIO_MODE_OUTPUT,

        .pull_up_en = GPIO_PULLUP_DISABLE,
        .pull_down_en = GPIO_PULLDOWN_DISABLE,

        .intr_type = GPIO_INTR_DISABLE
    };

    ESP_ERROR_CHECK(
        gpio_config(&motor_config)
    );


    // --------------------------------------------------------
    // SENSOR LASER
    // Activo LOW + pull-up
    // --------------------------------------------------------

    gpio_config_t laser_config = {
        .pin_bit_mask =
            (1ULL << PIN_SENSOR_LASER),

        .mode = GPIO_MODE_INPUT,

        .pull_up_en = GPIO_PULLUP_ENABLE,
        .pull_down_en = GPIO_PULLDOWN_DISABLE,

        .intr_type = GPIO_INTR_DISABLE
    };

    ESP_ERROR_CHECK(
        gpio_config(&laser_config)
    );


    // --------------------------------------------------------
    // LED
    // --------------------------------------------------------

    gpio_config_t led_config = {
        .pin_bit_mask =
            (1ULL << PIN_LED),

        .mode = GPIO_MODE_OUTPUT,

        .pull_up_en = GPIO_PULLUP_DISABLE,
        .pull_down_en = GPIO_PULLDOWN_DISABLE,

        .intr_type = GPIO_INTR_DISABLE
    };

    ESP_ERROR_CHECK(
        gpio_config(&led_config)
    );


    // --------------------------------------------------------
    // ESTADO INICIAL SEGURO
    // --------------------------------------------------------

    gpio_set_level(
        PIN_MOTOR_INB1,
        0
    );

    gpio_set_level(
        PIN_MOTOR_INB2,
        0
    );

    gpio_set_level(
        PIN_LED,
        1
    );
}


// ============================================================
// CONFIGURACION PWM
// ============================================================

static void configurar_pwm(void)
{
    ledc_timer_config_t timer_config = {

        .speed_mode = LEDC_LOW_SPEED_MODE,
        .timer_num = LEDC_TIMER_0,
        .duty_resolution = PWM_RESOLUTION,
        .freq_hz = PWM_FREQUENCY_HZ,
        .clk_cfg = LEDC_AUTO_CLK

    };

    ESP_ERROR_CHECK(
        ledc_timer_config(&timer_config)
    );


    ledc_channel_config_t channel_config = {

        .gpio_num = PIN_MOTOR_PWM,
        .speed_mode = LEDC_LOW_SPEED_MODE,
        .channel = LEDC_CHANNEL_0,
        .intr_type = LEDC_INTR_DISABLE,
        .timer_sel = LEDC_TIMER_0,
        .duty = 0,
        .hpoint = 0

    };

    ESP_ERROR_CHECK(
        ledc_channel_config(&channel_config)
    );
}


// ============================================================
// CONFIGURACION ADC
// ============================================================

static void configurar_adc(void)
{
    // --------------------------------------------------------
    // ADC1
    // --------------------------------------------------------

    adc1_config_width(
        ADC_WIDTH_BIT_12
    );


    // --------------------------------------------------------
    // GPIO36 / VP
    // ADC1_CHANNEL_0
    // POTENCIOMETRO
    // --------------------------------------------------------

    ESP_ERROR_CHECK(
        adc1_config_channel_atten(
            ADC1_CHANNEL_0,
            ADC_ATTEN_DB_11
        )
    );


    // --------------------------------------------------------
    // GPIO39 / VN
    // ADC1_CHANNEL_3
    // SENSOR DE BATERIA
    // --------------------------------------------------------

    ESP_ERROR_CHECK(
        adc1_config_channel_atten(
            ADC1_CHANNEL_3,
            ADC_ATTEN_DB_11
        )
    );
}


// ============================================================
// CONTROL PWM
// ============================================================

static void motor_pwm_set(float porcentaje)
{
    if (porcentaje < 0.0f)
        porcentaje = 0.0f;

    if (porcentaje > 100.0f)
        porcentaje = 100.0f;


    uint32_t duty =
        (uint32_t)((porcentaje / 100.0f) * PWM_MAX);


    ledc_set_duty(
        LEDC_LOW_SPEED_MODE,
        LEDC_CHANNEL_0,
        duty
    );


    ledc_update_duty(
        LEDC_LOW_SPEED_MODE,
        LEDC_CHANNEL_0
    );
}


// ============================================================
// MOTOR DETENIDO
// ============================================================

static void motor_detener(void)
{
    motor_pwm_set(0.0f);

    gpio_set_level(PIN_MOTOR_INB1, 0);
    gpio_set_level(PIN_MOTOR_INB2, 0);
}


// ============================================================
// MOTOR EN DIRECCION DE COMPRESION
// ============================================================

static void motor_comprimir(void)
{

    gpio_set_level(PIN_MOTOR_INB1, 1);
    gpio_set_level(PIN_MOTOR_INB2, 0);

    motor_pwm_set(PWM_MOTOR_INICIAL);
}


// ============================================================
// MOTOR EN DIRECCION DE DESCOMPRESION
// ============================================================

static void motor_descomprimir(void)
{
    /*
     * Direccion contraria a la compresion.
     */

    gpio_set_level(PIN_MOTOR_INB1, 0);
    gpio_set_level(PIN_MOTOR_INB2, 1);

    motor_pwm_set(PWM_MOTOR_INICIAL);
}

// ============================================================
// LEER SELECTOR
// ============================================================

static void leer_selector(
    bool *adulto,
    bool *infante,
    bool *ajustable
)
{
    /*
     * Selector activo LOW con pull-up:
     *
     * LOW  = seleccionado
     * HIGH = no seleccionado
     */

    *adulto =
        (gpio_get_level(PIN_MODO_ADULTO) == 0);

    *infante =
        (gpio_get_level(PIN_MODO_NINO) == 0);

    *ajustable =
        (gpio_get_level(PIN_MODO_AJUSTABLE) == 0);
}

// ============================================================
// SELECTOR EN OFF
// ============================================================

static bool selector_off(void)
{
    bool adulto;
    bool infante;
    bool ajustable;


    leer_selector(
        &adulto,
        &infante,
        &ajustable
    );


    return
        !adulto &&
        !infante &&
        !ajustable;
}


// ============================================================
// SELECTOR VALIDO
// ============================================================

static bool selector_valido(void)
{
    bool adulto;
    bool infante;
    bool ajustable;


    leer_selector(
        &adulto,
        &infante,
        &ajustable
    );


    int seleccionados =
        (adulto ? 1 : 0) +
        (infante ? 1 : 0) +
        (ajustable ? 1 : 0);


    return seleccionados <= 1;
}


// ============================================================
// SENSOR HOME
// ============================================================

static bool sensor_home(void)
{
    /*
     * Sensor laser activo LOW.
     *
     * LOW  = brazo en HOME
     * HIGH = brazo fuera de HOME
     */

    return (
        gpio_get_level(PIN_SENSOR_LASER) == 0
    );
}


// ============================================================
// LEER POTENCIOMETRO
// ============================================================

static float leer_frecuencia_ajustable(void)
{
    int raw = adc1_get_raw(ADC1_CHANNEL_0);


    float porcentaje =
        ((float)raw / 4095.0f) * 100.0f;


    float frecuencia =
        FRECUENCIA_MIN +
        (porcentaje / 100.0f) *
        (FRECUENCIA_MAX - FRECUENCIA_MIN);


    return frecuencia;
}


// ============================================================
// LEER VOLTAJE DE BATERIA
// ============================================================

static float leer_voltaje_bateria(void)
{
    int raw =
        adc1_get_raw(
            ADC1_CHANNEL_3
        );


    /*
     * Conversion actual:
     *
     * 0 - 4095 ADC
     *        ↓
     * 0 - 16 V bateria
     *
     * Se conserva la correccion de -0.3 V
     * utilizada en la version anterior.
     */

    float bateria =
        (
            ((float)raw / 4095.0f)
            * 16.0f
        )
        - 0.3f;


    return bateria;
}


// ============================================================
// EJECUTAR COMPRESION
// ============================================================

static bool ejecutar_compresion(void)
{
    /*
     * La compresion se controla por tiempo.
     *
     * El sensor HOME NO interviene durante
     * esta fase.
     */

    motor_comprimir();


    vTaskDelay(
        pdMS_TO_TICKS(
            TIEMPO_COMPRESION_S * 1000.0f
        )
    );


    motor_detener();


    return true;
}


// ============================================================
// EJECUTAR DESCOMPRESION
// ============================================================
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
void app_main(void)
{
    ESP_LOGI(
        TAG,
        "======================================"
    );

    ESP_LOGI(
        TAG,
        "       AUTO AMBU - VERSION 3.0"
    );

    ESP_LOGI(
        TAG,
        "======================================"
    );


    // --------------------------------------------------------
    // CONFIGURAR HARDWARE
    // --------------------------------------------------------

    configurar_gpio();

    configurar_pwm();

    configurar_adc();


    // --------------------------------------------------------
    // ESTADO SEGURO
    // --------------------------------------------------------

    motor_detener();

    ESP_LOGI(
        TAG,
        "Sistema inicializado"
    );


    // ========================================================
    // MAQUINA DE ESTADOS
    // ========================================================

    while (1)
    {
        switch (estado_actual)
        {
            // =================================================
            // INICIO
            // =================================================

            case ESTADO_INICIO:
            {
                bool adulto;
                bool infante;
                bool ajustable;


                leer_selector(
                    &adulto,
                    &infante,
                    &ajustable
                );


                // ---------------------------------------------
                // Selector invalido
                // ---------------------------------------------

                if (
                    (adulto && infante) ||
                    (adulto && ajustable) ||
                    (infante && ajustable)
                )
                {
                    entrar_estado(
                        ESTADO_ERROR
                    );

                    break;
                }


                // ---------------------------------------------
                // BUSCAR HOME DURANTE EL ARRANQUE
                // ---------------------------------------------

                if (!buscar_home_inicio())
                {
                    entrar_estado(
                        ESTADO_ERROR
                    );

                    break;
                }


                // ---------------------------------------------
                // HOME confirmado.
                //
                // Ahora debemos esperar que el selector
                // este en OFF antes de habilitar los modos.
                // ---------------------------------------------

                if (selector_off())
                {
                    entrar_estado(
                        ESTADO_OFF
                    );

                    break;
                }


                // ---------------------------------------------------------
                // Si el selector sigue en algun modo, permanecemos en
                // INICIO. Esto obliga a pasar por OFF antes de habilitar
                // cualquier modo.
                // ---------------------------------------------------------

                vTaskDelay(
                    pdMS_TO_TICKS(
                        ESTADO_TICK_MS
                    )
                );

                break;
            }


            // =================================================
            // OFF
            // =================================================

            case ESTADO_OFF:
            {
                bool adulto;
                bool infante;
                bool ajustable;


                motor_detener();


                leer_selector(
                    &adulto,
                    &infante,
                    &ajustable
                );


                // ---------------------------------------------
                // Combinacion imposible
                // ---------------------------------------------

                if (
                    (adulto && infante) ||
                    (adulto && ajustable) ||
                    (infante && ajustable)
                )
                {
                    entrar_estado(
                        ESTADO_ERROR
                    );

                    break;
                }


                // ---------------------------------------------
                // Seleccionar INFANTE
                // ---------------------------------------------

                if (infante)
                {
                    entrar_estado(
                        ESTADO_INFANTE
                    );

                    break;
                }


                // ---------------------------------------------
                // Seleccionar ADULTO
                // ---------------------------------------------

                if (adulto)
                {
                    entrar_estado(
                        ESTADO_ADULTO
                    );

                    break;
                }


                // ---------------------------------------------
                // Seleccionar AJUSTABLE
                // ---------------------------------------------

                if (ajustable)
                {
                    entrar_estado(
                        ESTADO_AJUSTABLE
                    );

                    break;
                }


                vTaskDelay(
                    pdMS_TO_TICKS(
                        ESTADO_TICK_MS
                    )
                );

                break;
            }


            // =================================================
            // INFANTE
            // =================================================

            case ESTADO_INFANTE:
            {
                float frecuencia =
                    FRECUENCIA_NINO;


                ESP_LOGI(
                    TAG,
                    "INFANTE: %.1f compresiones/min",
                    frecuencia
                );


                float bateria =
                    leer_voltaje_bateria();


                ESP_LOGI(
                    TAG,
                    "Bateria: %.2f V",
                    bateria
                );


                // ---------------------------------------------
                // Ejecutar ciclo
                // ---------------------------------------------

                if (!ejecutar_ciclo(frecuencia))
                {
                    entrar_estado(
                        ESTADO_ERROR
                    );

                    break;
                }


                // ---------------------------------------------
                // Al terminar el ciclo se verifica selector
                // ---------------------------------------------

                bool adulto;
                bool infante;
                bool ajustable;


                leer_selector(
                    &adulto,
                    &infante,
                    &ajustable
                );


                if (
                    (adulto && infante) ||
                    (adulto && ajustable) ||
                    (infante && ajustable)
                )
                {
                    entrar_estado(
                        ESTADO_ERROR
                    );

                    break;
                }


                if (selector_off())
                {
                    entrar_estado(
                        ESTADO_OFF
                    );

                    break;
                }


                if (adulto)
                {
                    entrar_estado(
                        ESTADO_ADULTO
                    );

                    break;
                }


                if (ajustable)
                {
                    entrar_estado(
                        ESTADO_AJUSTABLE
                    );

                    break;
                }


                break;
            }


            // =================================================
            // ADULTO
            // =================================================

            case ESTADO_ADULTO:
            {
                float frecuencia =
                    FRECUENCIA_ADULTO;


                ESP_LOGI(
                    TAG,
                    "ADULTO: %.1f compresiones/min",
                    frecuencia
                );


                float bateria =
                    leer_voltaje_bateria();


                ESP_LOGI(
                    TAG,
                    "Bateria: %.2f V",
                    bateria
                );


                // ---------------------------------------------
                // Ejecutar ciclo
                // ---------------------------------------------
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

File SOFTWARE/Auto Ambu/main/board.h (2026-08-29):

#ifndef BOARD_H
#define BOARD_H

// ============================================================
// SELECTOR DE MODOS
// ============================================================

#define PIN_MODO_ADULTO       13
#define PIN_MODO_NINO         23
#define PIN_MODO_AJUSTABLE    22

// ============================================================
// POTENCIOMETRO
// ============================================================

#define PIN_POTENCIOMETRO     36 // Probar tambien pin VP 36

// ============================================================
// PUENTE H
// ============================================================

#define PIN_MOTOR_PWM         26
#define PIN_MOTOR_INB1        14
#define PIN_MOTOR_INB2        27

// ============================================================
// SENSOR DE BATERIA
// ============================================================

#define PIN_BATERIA           39

#define PIN_SENSOR_LASER      33

// ============================================================
// LED
// Activo en LOW
// ============================================================

#define PIN_LED               19



// ============================================================
// MODOS
// ============================================================

#define FRECUENCIA_ADULTO     11.0f     // Resultados: cada 5.5s
#define FRECUENCIA_NINO       16.0f     // Resultados: cada 3.5s


// ============================================================
// TIEMPOS DEL MECANISMO
// ============================================================

// Tiempo que tarda el mecanismo en comprimir el Ambu
#define TIEMPO_COMPRESION_S       2.0f       // Recomendado 2s

// Tiempo que permanece completamente comprimido
#define TIEMPO_MANTENIMIENTO_S    0.0f

// Tiempo que tarda en descomprimir / regresar
#define TIEMPO_DESCOMPRESION_S    0.05f      // Recomendado 0.1s

// ============================================================
// MOTOR
// ============================================================

// PWM inicial para las pruebas.
// Posteriormente será reemplazado por el cálculo dinámico
// basado en el voltaje de batería.
#define PWM_MOTOR_INICIAL          100.0f

// ============================================================
// POTENCIOMETRO
// ============================================================

// Rango de frecuencia para el modo ajustable.
// Se puede modificar posteriormente.
#define FRECUENCIA_MIN             5.0f
#define FRECUENCIA_MAX             16.0f

#endif

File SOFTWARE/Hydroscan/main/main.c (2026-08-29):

// Hydroscan main application file v5.0.4
// Made by Isaias Matos

// CAMBIOS v5.0.4 Parte II
// OBJETIVO: Probar todo nuevamente con el modulo ya acoplado a la placa PCB.
// Parametros: 
//      Sensor de oleaje: frecuencia de muestreo a 5 Hz, tiempo de rafaga a 120 s. Alta resolucion.
//      Duracion de rafaga de oleaje: 120 s
//      Duracion de espera entre rafagas de oleaje: 120s
//      Periodo de actualizacion de datos de oleaje: 60 s
//      Periodo de actualizacion de GPS: 90 s
//      Periodo de actualizacion para envios a Firebase: 180 s
// ARCHIVOS MODIFICADOS: 
//      Actualizado pines de la board.
// RESULTADOS: 
//      EL modem ya conecta y reconoce la tarjeta SIM.
//      El GPS ya obtiene la posicion y la guarda en buoy_data.
//      Agregado sistema mutex para evitar conflictos entre tareas de gps y firebase.
//      El modem ya obtienen IP y API
//      El modem ya envia DATOS COMPLETOS a Firebase.
//          Probado en la placa PCB: Sensores TDS y Temp, correcto envio a firebase, bateria funcional.
// NOTA: Recomendable hacer mas pruebas del oleaje
// NOTA: Sistema actual requiere tener gps antes de enviar datos a firebase.

// A MEJORAR EN v5.1 y versiones futuras
//      Recibir datos de firebase
//      Probar sistema final con todos los sensores y el modem

#include <stdio.h>

#include "freertos/FreeRTOS.h"
#include "freertos/task.h"
#include "esp_log.h"

#include "buoy_data.h"
#include "tds_sensor.h"
#include "ds18b20_sensor.h"
#include "telemetry.h"
#include "wave_task.h"

#include "modem.h"
#include "gps.h"
#include "firebase.h"

#include "utilities.h"
#include <time.h>

static const char *TAG = "MAIN";

// PARAMETROS GPS - FIREBASE - WAVE
#define GPS_UPDATE_PERIOD_MS          90000      // 90 s
#define FIREBASE_UPDATE_PERIOD_MS     180000     // 120 s de wave_burst_duration + 60 s de wave_last_update
#define TIME_SINCE_LAST_WAVE_UPDATE   60000      // 60 s la mitad de wave_burst_duration

#define LAMP_PIN                      11

static void modem_task(void *pvParameters);

static void update_lamp(void);


buoy_data_t buoy_data;


/*==============================================================
                    LAMPARA
==============================================================*/

static void update_lamp(void)
{
    gpio_set_direction(LAMP_PIN, GPIO_MODE_OUTPUT);

    uint32_t local_timestamp = (uint32_t)buoy_data.timestamp;

    int hour = local_timestamp / 10000;
    int min  = (local_timestamp / 100) % 100;

    bool night = ((((hour >= 17) & (min >= 10)) || hour < 6));

    gpio_set_level(LAMP_PIN, night ? 1 : 0);

    ESP_LOGI(TAG,
             "Hora local: %02d:%02d | Lampara: %s",
             hour,
             min,
             night ? "ON" : "OFF");
}

/*==============================================================
                    MODULO DE COMUNICACION
==============================================================*/

static void modem_task(void *pvParameters)
{
    TickType_t lastGps = xTaskGetTickCount();
    TickType_t lastFirebase = xTaskGetTickCount();

    bool gps_ok = false;

    bool recent_wave_data = false;

    while (1)
    {
        TickType_t now = xTaskGetTickCount();

        /*------------------------------------------
                ACTUALIZAR GPS
        ------------------------------------------*/

        if ((now - lastGps) >= pdMS_TO_TICKS(GPS_UPDATE_PERIOD_MS))
        {
            lastGps = now;

            ESP_LOGI("MODEM_TASK", "Updating GPS...");

            gps_update();   

            gps_ok = gps_has_fix();

            if(gps_ok)
            {
                ESP_LOGI("MODEM_TASK", "GPS FIX OK");

                update_lamp();
            }
            else
            {
                ESP_LOGW("MODEM_TASK", "GPS without FIX");
            }
        }

        /*------------------------------------------
                SUBiR DATOS A FIREBASE
        ------------------------------------------*/

        if ((now - lastFirebase) >= pdMS_TO_TICKS(FIREBASE_UPDATE_PERIOD_MS))
        {
            lastFirebase = now;

            recent_wave_data = (buoy_data.wave_height.last_update_ms <= TIME_SINCE_LAST_WAVE_UPDATE 
                && buoy_data.wave_period.last_update_ms <= TIME_SINCE_LAST_WAVE_UPDATE);    // FUNCIONA!!!!!!

            if(gps_ok && recent_wave_data)
            {
                ESP_LOGI("MODEM_TASK", "Uploading Firebase...");

                firebase_send();
            }
            else
            {
                ESP_LOGW("MODEM_TASK",
                         "Firebase skipped (No GPS FIX)");
            }
        }

        vTaskDelay(pdMS_TO_TICKS(250));
    }
}

/*==============================================================
                        PRINCIPAL
==============================================================*/
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

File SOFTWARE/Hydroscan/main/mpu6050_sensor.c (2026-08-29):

/*
 * ============================================================
 *                      HYDROSCAN
 * ------------------------------------------------------------
 * Archivo      : mpu6050_sensor.c
 * Descripción  : Driver del sensor MPU6050
 * ============================================================
 */

#include "mpu6050_sensor.h"

#include <math.h>
#include <string.h>

#include "driver/i2c.h"
#include "esp_log.h"
#include "esp_err.h"

//#include "board.h"

/*==============================================================
                        CONFIGURACIÓN
==============================================================*/

static const char *TAG = "MPU6050";

/* Direccion I2C */

#define MPU6050_ADDR           0x68

/* Registros */

#define MPU_PWR_MGMT_1         0x6B
#define MPU_SMPLRT_DIV         0x19
#define MPU_CONFIG             0x1A
#define MPU_GYRO_CONFIG        0x1B
#define MPU_ACCEL_CONFIG       0x1C
#define MPU_ACCEL_XOUT_H       0x3B

/*==============================================================
                        CONFIGURACIÓN I2C
==============================================================*/

#define MPU6050_I2C_PORT      I2C_NUM_0
#define MPU6050_SDA_PIN       9
#define MPU6050_SCL_PIN       8
#define MPU6050_I2C_FREQ_HZ   100000


/*==============================================================
                        VARIABLES
==============================================================*/

static float gx_bias = 0.0f;
static float gy_bias = 0.0f;
static float gz_bias = 0.0f;

static float ax_offset = 0.0f;
static float ay_offset = 0.0f;
static float az_offset = 0.0f;

/*==============================================================
                    FUNCIONES PRIVADAS
==============================================================*/

static esp_err_t i2c_write_byte(uint8_t reg, uint8_t data)
{
    i2c_cmd_handle_t cmd = i2c_cmd_link_create();

    i2c_master_start(cmd);

    i2c_master_write_byte(cmd,
                          (MPU6050_ADDR << 1) | I2C_MASTER_WRITE,
                          true);

    i2c_master_write_byte(cmd, reg, true);

    i2c_master_write_byte(cmd, data, true);

    i2c_master_stop(cmd);

    esp_err_t ret =
        i2c_master_cmd_begin(MPU6050_I2C_PORT,
                             cmd,
                             pdMS_TO_TICKS(1000));

    i2c_cmd_link_delete(cmd);

    return ret;
}

/*------------------------------------------------------------*/
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

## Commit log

2026-06-11 primer commit HydroScan V1
    [HydroScan_V1.kicad_pcb, HydroScan_V1.kicad_sch]
2026-06-11 Organizacion de trabajo
    [BQ25790_BQ25792_BQ25672_V1p0_Schematic Checklist (14).xlsx, HydroScan_V1.kicad_pcb, HydroScan_V1.kicad_sch]
2026-06-14 PCB dimensions
    [HydroScan_V1.kicad_pcb, HydroScan_V1.kicad_sch]
2026-06-14 Edit of schematic
    [HydroScan_V1.kicad_sch]
2026-06-15 Integrate ESP32
    [HydroScan_V1.kicad_pcb, HydroScan_V1.kicad_pcb_bom.csv, HydroScan_V1.kicad_pcb_positions.csv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]
2026-06-16 Aclaracion de avances
    [HydroScan_V1.kicad_pcb, HydroScan_V1.kicad_sch]
2026-06-18 Avances puerto USB C
    [HydroScan_V1.kicad_pcb, HydroScan_V1.kicad_sch]
2026-06-18 Avances v1
    [HydroScan_V1.kicad_pcb]
2026-06-18 change 2
    [HydroScan_V1.kicad_sch]
2026-06-19 EsP32 terminate
    [HydroScan_V1.kicad_pcb, HydroScan_V1.kicad_sch]
2026-06-19 cambios en el fast charging
    [HydroScan_V1.kicad_pcb, HydroScan_V1.kicad_sch]
2026-06-20 USB c and Fast chargin update finish
    [HydroScan_V1.kicad_pcb, HydroScan_V1.kicad_sch]
2026-06-21 update of charging and logic
    [HydroScan_V1.kicad_sch]
2026-06-22 power updating
    [HydroScan_V1.kicad_pcb, HydroScan_V1.kicad_sch]
2026-06-23 powering rooting finish
    [HydroScan_V1.kicad_pcb, HydroScan_V1.kicad_sch]
2026-06-24 Update of design the power
    update of charging
    [HydroScan_V1.kicad_pcb, HydroScan_V1.kicad_sch]
2026-06-25 latest updates
    [HydroScan_V1.kicad_pcb, HydroScan_V1.kicad_sch]
2026-07-02 Hydrofish
    update pcb
    [HydroScan_V1.kicad_pcb]
2026-07-06 correction of errors DRC
    [HydroScan_V1.kicad_pcb, HydroScan_V1.kicad_sch]
2026-07-09 Update of power desing
    [HydroScan_V1.kicad_pcb, HydroScan_V1.kicad_pcb_bom.csv, HydroScan_V1.kicad_pcb_positions.csv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]
2026-07-09 squematic update of USB 15V
    [HydroScan_V1.kicad_pcb, HydroScan_V1.kicad_sch]
2026-07-11 update of desing Ambu and hydro
    [HydroScan_V1.kicad_pcb, HydroScan_V1.kicad_sch]
2026-07-11 update dates of diameter
    [HydroScan_V1.kicad_pcb]
2026-07-12 DRC update
    [HydroScan_V1.kicad_pcb, HydroScan_V1.kicad_sch]
2026-07-12 PCB_v1
    manufacturing list
    [HydroScan_V1.kicad_pcb, HydroScan_V1.kicad_sch]
2026-07-13 BOM generate
    [Fabrication_V1_bom.csv, Fabrication_V1_designators.csv, Fabrication_V1_positions.csv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]
2026-07-15 Document manufacturing organization
    [Fabrication_V1_bom.csv, Fabrication_V1_designators.csv, Fabrication_V1_positions.csv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]
2026-07-19 Schematic documentation
    hardware information
2026-07-19 Schematic documentation 1.0V
2026-07-19 Schematic documentation 1.1V
2026-07-22 3D update
    [HydroScan_V1.kicad_pcb]
2026-07-25 Revise README for HydroScan and AUTOAMBU projects
    Updated project descriptions and added new badges for HydroScan and AUTOAMBU. Enhanced telemetry and power management details.
2026-07-25 Update KiCad version in README badges
    Updated KiCad version in hardware badge from 8 to 10.
2026-07-26 hardware update notes
    [HydroScan_V1.kicad_sch]
2026-08-07 documents update
    [HydroScan_V1.kicad_pcb]
2026-08-09 PCB usb c vertical
    [PCB usb C up.kicad_pcb, PCB usb C up.kicad_sch]
2026-08-19 name update
    [HydroScan_V1.kicad_sch]
2026-08-19 logo en 3D
    [AUTO_AMBU_60mm_alta_resolucion_base_logo.stl]
2026-08-19 soporte bateria
    [soporte para bateria ambu revisado.SLDPRT]
2026-08-19 engranaje de brazo
    [engranaje_con_brazo - copia.SLDPRT]
2026-08-19 agarradera de acrilico
    [agarradera de acrilico.SLDPRT]
2026-08-19 3D design
    [base para ambú.SLDPRT, elevador de ejes.SLDPRT, panel acrilico 2.SLDPRT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]
2026-08-19 Ensamblaje 3D
    [Ensamblaje_ambu_nuevo.SLDASM]
2026-08-19 Tesis de AMBU
2026-08-20 paul puse el datasheet
2026-08-30 Update DESIGN OF AMBU
    [AUTO_AMBU_60mm_alta_resolucion_base_logo.stl, Ensamblaje_ambu_nuevo.SLDASM, Tapa_Superior_AMBU.SLDPRT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]
2026-08-30 UPDATE OF DESING AMBU ACRILICO
    [panel acrilico 2.SLDPRT, soporte circunferencia pequeña ambu.SLDPRT]
2026-08-30 3D DESIGN AMBU UPDATE 3
    [Ensamblaje_ambu_nuevo.SLDASM, base para ambú.SLDPRT]
